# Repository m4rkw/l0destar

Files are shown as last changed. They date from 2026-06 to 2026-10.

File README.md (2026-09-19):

# l0destar

[l0destar.com](https://l0destar.com) A fully open-source vehicle tracker - open hardware and open software.

Inspired by the [Geolink Opentracker](https://github.com/geolink/opentracker/) and the [Fortebit Polaris](https://www.fortebit.tech/polaris/), the goal is to build something that will last: a reference design for the best possible vehicle tracker that anyone can fab, modify, and host. Hardware and software are completely open and maintained as a community project.

## Status

Prototyping / design phase. The v2.1 layout worked on a bench, and v2.6 (CAN,
K-line and micro), v3.0, v3.1, v3.2 and v3.3 have since been built and bench
tested - see the test status table in each board's README. v3.4 is designed
but not yet built or tested.

<strong>All boards before v3.3 have a serious defect in the K-wire circuit
if the L wire is connected. If any of these prototypes are built the L wire
should not be connected to the vehicle as if it was ever externally shorted
to the 12V rail the l0destar device would be damaged.</strong> Luckily very
few people are going to care at all about this ancient protocol and even fewer
will ever need the L wire in normal use but it still bears mentioning as an
indication that these are very much prototypes and there may be other
undiscovered defects.

## Disclaimer

This is a prototype, not a product. Nothing here is validated, qualified or certified, the parts lists are examples rather than a verified BOM, and any test results are my own unverified bench observations. All responsibility for anything built from it rests with the person building and installing it.

**Before building, installing or relying on any of this, read the [full disclaimer](DISCLAIMER.md).**

## What it is

- **Mission** - the world's best fully open-source vehicle tracker, no profit motive. See [`MISSION.md`](MISSION.md).
- **Goals** - KiCad reference design, open enclosure CAD, open firmware and server, weeks of standby on a typical car battery, 1 Hz GNSS, LTE-M/NB-IoT, CAN + K-Line diagnostics, accelerometer-driven wake. Full list in [`GOALS.md`](GOALS.md).
- **Technology choices** - Nordic nRF9151 SiP (LTE-M/NB-IoT + GNSS), LT8609A buck, ASM330LHHX IMU, MCP2518FD + TCAN3414 CAN, TJA1027T K-Line. Rationale and trade-offs in [`TECHNOLOGY.md`](TECHNOLOGY.md).

## License

l0destar is multi-licensed by artifact type - permissive across the board:

| Artifact | License |
|---|---|
| Hardware design files | `CERN-OHL-P-2.0` |
| Firmware | `Apache-2.0` |
| Server-side software | `Apache-2.0` |
| Documentation, enclosure CAD, media | `CC-BY-4.0` |

Full text and rationale in [`LICENSE.md`](LICENSE.md); license bodies in [`LICENSES/`](LICENSES/).

## Contributing

Contributions are welcome. l0destar uses the [Developer Certificate of Origin](https://developercertificate.org/) rather than a CLA - every commit must carry a `Signed-off-by:` trailer (`git commit -s`). See [`CONTRIBUTING.md`](CONTRIBUTING.md) for PR expectations.

## Contact

- Bug reports and feature ideas: [GitHub Issues](https://github.com/m4rkw/l0destar/issues)
- Open-ended questions and design discussion: [GitHub Discussions](https://github.com/m4rkw/l0destar/discussions)
- Direct contact: [contact me](https://l0destar.com/contact.html)

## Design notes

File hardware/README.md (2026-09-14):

# l0destar hardware

**Before building, installing or relying on any of this, read the [project disclaimer](../DISCLAIMER.md).**

## Overview

KiCad PCB designs for the l0destar vehicle tracker. All boards are built around
the Nordic nRF9151 for LTE-M/GPS and share a common set of subsystems: 12V
automotive power input, INA228 voltage monitoring, ignition sensing, and an
accelerometer/IMU.

**THESE SHOULD NOT BE CONSIDERED FINISHED PRODUCTS. SOME OF THEM HAVEN'T BEEN
TESTED AT ALL. USE ENTIRELY AT YOUR OWN RISK.**

**SOME OF THESE HAVE KNOWN DEFECTS DETAILED IN THEIR README**

Prototypes here are currently being tested and evaluated, there are typically a
few in the pipeline at any given time. Older boards no longer being tested are
moved into the [archive](archive/).

## PCB designs

### v3.1 - input resilience, hardened antenna feed, aux rail fault detection

- **[l0destar v3.1](l0destar_v3.1/)** - v3.0 with more robust input protection
  (sized for ISO 7637-2 pulse 2a), auxiliary power rail sensing/fault
  detection, and a hardened antenna feed with 15R series resistance and ESD
  protection. Same footprint as v3.0. Tested - 130 µA quiescent, all major
  subsystems passed.

### v3.2 - MCU over-voltage protection

- **[l0destar v3.2](l0destar_v3.2/)** - v3.1 plus hardware over-voltage
  protection that disconnects the module supply within microseconds of a
  regulator fault (self-recovering, no firmware dependency, ~10 µA), and I2C
  bus hardening against LTE TX bursts (stronger pull-ups, 100pF filter caps
  on SDA/SCL, series jumper/ferrite on the accelerometer supply).

  Tested successfully: <a href="https://www.youtube.com/watch?v=6-iVvQPaaeg">OVP scope test</a>.
  134 µA quiescent with firmware 0.4.26 (140.8 µA before it moved the sleep
  wake interrupts off the GPIOTE channels).

### v3.3 - L-line defect fix

- **[l0destar v3.3](l0destar_v3.3/)** - fixes the L-line short-to-battery
  defect present in v3.0-v3.2 (pulldown current limited to 90 mA via an
  AL5809-90, gate-fault current into the nRF limited) and adds L-line fault
  sensing so a 12V short can be detected. Buck converter tuned to shut off
  cleanly below ~4.3V and restart only above ~5.6V to avoid flapping. Built and
  bench tested: 146.2 µA quiescent as built, 43.7 µA with the accelerometer's
  NC pads scraped off.

### v3.4 - accelerometer fix

- **[l0destar v3.4](l0destar_v3.4/)** - v3.3 with the accelerometer's NC pins
  left unconnected (grounded on v3.0-v3.3, which kept the part out of its
  low-power state), the buck enable divider made optional, test points added
  and a TCAN3414DR CAN transceiver specified. Not yet built or tested; ~35.5 µA
  quiescent expected at 12V.

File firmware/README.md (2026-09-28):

# l0destar firmware

**Before building, installing or relying on any of this, read the [project disclaimer](../DISCLAIMER.md).**

Automotive telemetry tracker firmware for the **Nordic nRF9151** SiP (LTE-M +
GNSS), built on Zephyr RTOS via the nRF Connect SDK (NCS). It reports position,
speed, battery and ignition state to a back-end over an encrypted link, sleeps
deeply when the vehicle is parked, and wakes on movement, ignition, or a timer.

> Ported from the original Arduino/Polaris `*.ino` firmware. Where a module
> replaces a legacy one, its header comment notes the original source file.

---

## Hardware

| Function | Part / detail |
|---|---|
| MCU / modem / GNSS | nRF9151 SiP (LTE-M, integrated GNSS receiver) |
| IMU | ASM330LHHX (automotive 6-axis, WHO_AM_I 0x6B) over bit-banged I²C - accelerometer for movement detection, the wake interrupt and impacts; gyro in telemetry and impact alerts; FIFO as a ring of recent samples; MLC/FSM unused |
| Voltage monitor | INA228 over the same I²C bus - battery / ignition-derived voltage |
| Diagnostics | K-wire (ISO 14230-1 K-line, KWP2000) via TJA1027T on v3.x (L9637D on v2.x); 5-baud address bit-banged, data bytes on UARTE1 — see [KWIRE.md](KWIRE.md) |
| Ignition sense | GPIO input (MOSFET-gated 3.3 V rail) |
| Status LED | board `led0` alias (LED1 on the nRF9151 DK) |

Builds target the **Makerdiary nRF9151 Connect Kit** (`nrf9151_connectkit/nrf9151/ns`),
which every l0destar carrier board is built around; `PROFILE=dk` builds for the
nRF9151 DK instead. Pin assignments come from `Kconfig.boards` and are given
names in `src/pins.h`; DK-specific peripheral conflicts are resolved in
`boards/nrf9151dk_nrf9151_ns.overlay` (+ `.conf`).

### Carrier boards

Every l0destar PCB carries the same Connect Kit but lands each signal on a
different header pin and wires the switched power rails differently.
`Kconfig.boards` defines one selectable definition per PCB - GPIO map,
fitted-hardware flags, and power-domain topology, all extracted from the KiCad
designs in `../hardware/`. Select the board in `local.conf` and everything
else follows:

```
CONFIG_APP_BOARD_L0DESTAR_V3_0=y
```

Available: `APP_BOARD_BENCH`, `..._L0DESTAR_V2_1`, `..._V2_1_MINI`,
`..._V2_5_CAN/_KLINE/_MICRO`, `..._V2_6_CAN/_KLINE/_MICRO`, `..._V3_0`,
`..._V3_1`, `..._V3_2`, `..._V3_3`, `..._V3_4` (default).
Individual pins/flags can still be overridden after the board defaults apply
(on v3.0, set `CONFIG_APP_BOARD_HAS_CAN=n` or `..._HAS_KLINE=n` to match the
jumper configuration of the physical board).

Selecting a board also arms the **power-domain sequencing** in
`src/hw_domain.c`. Signals that terminate inside a switched rail (CAN SPI
pins, K-line pins) are parked as input+pulldown whenever that
rail is off and only released while it is powered - a pin driven high into an
unpowered MCP2518FD/TXS0104E would backfeed the dead rail through its ESD
clamp diodes (abs max VDD + 0.3 V), and the CAN_INT/CAN_CS/K-line pull-ups
live on the switched rails, so they float when the domain is down. On boards
with transceiver standby control (v2.5C/v2.6C, and v3.0 onwards),
`src/hw_can.c` configures MCP2518FD `IOCON.XSTBYEN` at boot so sleep mode
automatically drops the transceiver into standby - required on v2.5/v2.6
where the CAN rail shares the GPS AUX domain and stays powered during
engine-off telemetry wakes.

---

## Architecture

`main()` initialises the peripherals, modem, GNSS and watchdog, then runs a
state machine:

```
            ┌───────────────────────────── engine on ──────────────┐
            ▼                                                        │
  IDLE ──► GPS_COLLECT ──► SEND ──┬─► (ignition off) ─────► SLEEP    │
   ▲                              ├─► (engine off)  ─► IGNITION_SLEEP┘
   └──────────────────────────────┘
```

- **IDLE** – wait for network registration, poll ignition + battery, decide when to send.
- **GPS_COLLECT** – acquire a GNSS fix, build and buffer a telemetry record.
- **SEND** – transmit batched telemetry over encrypted UDP, process any server command.
- **IGNITION_SLEEP** – ignition on but engine off: periodic sends, watch for engine start / ignition off.
- **SLEEP** – ignition off: peripherals powered down; wakes on the IMU's movement interrupt, ignition change, or telemetry timer.

Extras handled in the loop: **movement alarm** with escalating cooldowns,
**coast-to-stop** (keep reporting briefly after ignition-off while still
rolling), and **modem recovery**: registered but unable to send for
`APP_MODEM_STUCK_CFUN_S` (10 min) brings a CFUN cycle, and for
`APP_MODEM_STUCK_RESET_S` (30 min) a modem library restart. Losing coverage is
left to the modem.

### Impact detection

While awake the IMU runs at ±8 g with a high-g interrupt
(`APP_CRASH_THRESHOLD_MG`, default 4 g - set ~1200 in `local.conf` and rap the
desk to bench-test) and batches accel+gyro at 26 Hz into the chip's 3 KB FIFO
ring (~9 s of history). On impact, the ring is drained and an alert is sent
with peak g (per-axis), peak rotation rate, disturbance duration, and speed;
the ±0.5 s waveform around the peak is dumped to the serial log. While asleep,
a short, sharp hit above `APP_IMPACT_IMMEDIATE_MG` (default 700 mg) is reported
at once, and an unconfirmed movement wake whose peak exceeds
`APP_PARKED_IMPACT_MG` (default 800 mg) raises a `parked impact` alert instead
of being ignored. Telemetry `ax/ay/az` are **milli-g** (FS-independent);
`gx/gy/gz` are bias-corrected LSB at ±250 dps.

### Source layout (`src/`)

| File | Description |
|---|---|
| `main.c` | Entry point, state machine, sleep/wake, movement + coast logic |
| `modem.c` | LTE-M bring-up, registration, APN, RAI, cell-info tracking, error recovery |
| `gnss.c` | GNSS fixes via the nRF9151's built-in receiver (`nrf_modem_gnss`) |
| `agnss.c` | A-GNSS assistance from **nRF Cloud REST** (device-JWT auth) |
| `transport.c` | UDP telemetry, each datagram sealed with **ChaCha20-Poly1305** under the device key |
| `traccar.c` | Built in its place with `CONFIG_APP_TRACCAR`: the same lines as OsmAnd-protocol HTTP requests to a **Traccar** server ([TRACCAR.md](TRACCAR.md)) |
| `data.c` | Telemetry CSV record builder (position, speed, battery, ignition, accel) |
| `commands.c`  | Server command dispatch (`key=value[,…]`) |
| `alert.c` | Movement/event alert queue (piggybacks on sends, or standalone) |
| `settings.c`  | Runtime settings (in-memory; Kconfig-backed defaults) |
| `crypto.c` | ChaCha20-Poly1305 through PSA Crypto, CSPRNG, PSK hex parsing |
| `hw_common.c` | GPIO init + bit-banged I²C bus |
| `hw_domain.c` | Switched power-domain sequencing (park/release of pins in AUX/OBD/K domains) |
| `hw_power.c`  | INA228 voltage, ignition read, INA shutdown/wake, AUX domain wrappers |
| `hw_can.c` | MCP2518FD power/domain handling, sleep mode + transceiver standby (XSTBY) |
| `hw_accel.c`  | ASM330LHHX IMU (accel path): polling + hardware wake interrupt |
| `hw_kline.c`  | K wire: 5-baud init bit-banged, data bytes on UARTE1; vehicle discovery and the runtime session ([KWIRE.md](KWIRE.md), [KWIRE_QUICKSTART.md](KWIRE_QUICKSTART.md)) |
| `kline_obd.c` | OBD-II over the K wire: PID polling into telemetry, fault codes, engine/speed for the tracker's own logic; the fast rotating poll for track mode ([TRACK_MODE.md](TRACK_MODE.md)) |
| `obd_alert.c` | Threshold alerts on OBD telemetry: the `CONFIG_APP_OBD_ALERTS` rule list judged after every poll, one alert per crossing with a clear on the way back |
| `fota.c` | Over-the-air updates: manifest check, battery gate, MCUboot image download ([FOTA.md](FOTA.md)) |
| `databuf.c` | Backlog of records that could not be sent, kept until the link comes back |
| `dbglog.c` | Keeps warnings and errors in RAM and sends them with the next record that gets through |
| `fatal.c` | Fatal error handler: reboots instead of halting, leaving a note for the next record's `rst=` field |
| `hw_selftest.c` | Boot-time switched-rail self-test (v3.1+) |
| `board_test.c` · `lte_power_test.c` · `can_bench.c` | Bench builds only: the interactive board test run by `board_test.sh` · LTE transmit power and brown-out rig · CAN bench-test agent |
| `led.c` · `watchdog.c` · `reboot.c` | Status LED · 32 s task watchdog (HW fallback) · reboot helper |
| `config.h` · `pins.h` · `app.h` · `ca_cert.h` | Compile-time defaults · names for the `APP_PIN_*` pins · shared API/state · server CA cert, generated from `certs/ca.crt` by `build.sh` and not in git |

---

## Connectivity & telemetry

Telemetry is **plain UDP**, each datagram sealed with **ChaCha20-Poly1305**
under the device's 32-byte key, `CONFIG_APP_PSK_HEX` (`transport.c`,
`crypto.c`). The server holds the same key for the device's IMEI, so a datagram
that decrypts is authenticated as well as private.

- Endpoint: `CONFIG_APP_SERVER_HOST` : `CONFIG_APP_SERVER_PORT` (**65480**).
- Request: `[1] IMEI length` `[n] IMEI` `[12] nonce` `ciphertext` `[16] tag`, with
  the IMEI as associated data. Response: `[12] nonce` `ciphertext` `[16] tag`,
  bound to the IMEI and the request's nonce. See
  [PROTOCOL.md](../server/docs/PROTOCOL.md).
- `modem.c` enables release assistance (`AT%RAI`), so the radio is released
  soon after each exchange and GNSS gets the shared antenna back.
- Delivery is confirmed, not assumed. The modem accepting a datagram only
  means it is queued, and a modem that loses its registration discards what
  it holds, so each send's records are kept until the server's reply to that
  datagram comes back (the reply is bound to the request's nonce, so it names
  the datagram) and sent again from the backlog if it has not within
  `APP_ACK_TIMEOUT_S` (`databuf.c`). The server drops the copy of anything
  that did arrive, and a record sent late carries `age=` so it is filed at
  the time it was built. A drive that loses the network keeps recording into
  the backlog.

The CA in `src/ca_cert.h` is for updates only: `modem.c` writes it into the
modem on first boot, and the update server's certificate is checked against it.

**Traccar** instead of the l0destar server: `CONFIG_APP_TRACCAR=y` with
`CONFIG_APP_TRACCAR_HOST` builds `src/traccar.c` in place of `transport.c`,
and every record, alert and fault-code report goes to a
[Traccar](https://www.traccar.org) server as an OsmAnd-protocol HTTP request
(port 5055), with the device's IMEI as its identifier. Records, batching and
the backlog are unchanged; Traccar's *custom* command reaches the firmware's
command parser. What the l0destar server does that Traccar cannot — settings
from the server, track mode, update adverts, the device log, encryption — is
in [TRACCAR.md](TRACCAR.md), with the field mapping.

Each telemetry record is one CSV line built in `data.c` (timestamp, lat, lon,
speed, altitude, heading, HDOP, satellites, battery, ignition, uptime and
power-on flag, then extras such as the accelerometer;
[PROTOCOL.md](../server/docs/PROTOCOL.md) lists them all). Records batch by `BATCH_SIZE` (`CONFIG_APP_BATCH_SIZE`,
default 3 while driving: each send costs an RRC connection and a GNSS
re-acquisition, so three records a datagram roughly doubles the record rate
for a page update every few seconds; ignition changes and settings syncs
still flush at once).

---

## GNSS & A-GNSS (nRF Cloud)

GNSS fixes come from the nRF9151's built-in receiver. A cold fix with no cached
ephemeris can take 2–5 minutes (it time-shares the antenna with LTE), so the
firmware optionally fetches **A-GNSS** assistance from nRF Cloud to speed up
time-to-first-fix.

`agnss.c` authenticates to nRF Cloud's REST API with a **per-device JWT** signed
by a key in the modem at `CONFIG_NRF_CLOUD_SEC_TAG` (default `16842753`). nRF
Cloud only accepts that JWT once the device has been **onboarded** to your
account - otherwise the request fails with `401 / 40100 "Auth token is
malformed"`. See **[nRF Cloud device provisioning](#nrf-cloud-device-provisioning)**.

> A-GNSS is an optimisation, not a dependency: GNSS still cold-fixes without it.

---

## Building

Requires [nRF Connect SDK **v3.3.0**](https://docs.nordicsemi.com/) where nRF
Util's sdk-manager installs it: `/opt/nordic/ncs/v3.3.0` on macOS, `~/ncs/v3.3.0`
on Linux (override with `NCS_ROOT`). Builds target the Connect Kit; `PROFILE=dk`
builds for the nRF9151 DK, and `BOARD` overrides the target.

```sh
./build.sh            # incremental build  -> build/merged.hex
./build.sh pristine   # clean rebuild
```

`build.sh` runs `west build` inside the NCS toolchain. It layers `local.conf`,
and stops if there is none unless `LOCAL_CONF` is set empty; `PROV=1` adds
`prov.conf` on top.

### Configuration layers

| File | Committed | Purpose |
|---|---|---|
| `prj.conf` | yes | Zephyr/NCS subsystem config (modem, sockets, crypto, logging, PM) |
| `Kconfig`  | yes | Application symbols + defaults (see table below) |
| `boards/nrf9151dk_nrf9151_ns.{conf,overlay}` | yes | Board-specific Kconfig + devicetree (disables conflicting DK peripherals) |
| `boards/nrf9151_connectkit_nrf9151_ns.conf` | yes | Connect Kit builds: turns on the modem antenna library and sends `AT%XCOEX0`, which powers the GNSS amplifier |
| `local.conf` | **no** (git-ignored) | Per-deployment secrets / overrides |
| `prov.conf`  | yes | Provisioning-build overlay (AT-host bridge) - enabled via `PROV=1` |

The full list, with `remote.conf`, `sysbuild.conf` and `pm_static.yml`, is in
[firmware build options](../docs/reference/firmware.md).

### local.conf

`local.conf` is git-ignored; create it with at least the board, the server, the
APN and the device key:

```
CONFIG_APP_BOARD_L0DESTAR_V3_4=y
CONFIG_APP_SERVER_HOST="tracker.example.com"
CONFIG_APP_APN="iot.example.net"
CONFIG_APP_PSK_HEX="<64 hex characters>"
```

Any `APP_*` symbol from `Kconfig` can be overridden here (see the reference
table). `CONFIG_APP_PSK_HEX` is required: the server decrypts this device's
telemetry with the same key, which it is given when the device is enrolled
(`openssl rand -hex 32` makes one).

### Flashing

```sh
./flash.sh                          # program over the Connect Kit's CMSIS-DAP probe
./reset.sh                          # reboot without reflashing
```

Both use pyocd and end with a pin reset: pyocd's default soft reset leaves the
nRF9151 in debug interface mode, drawing milliamps while asleep.
[QUICKSTART.md](QUICKSTART.md) explains why they also stop pyocd erasing a
protected part.

---

## Over-the-air updates

The build carries **MCUboot** (`sysbuild.conf`), which splits the 1 MB flash
into two 416 KB slots pinned by `pm_static.yml`. `fota.c` checks for an update
at power-on, when sent the `fota` command, and at the next safe moment after a
telemetry reply advertises a newer version (`fota=<version>`). It fetches its
own manifest from the update server (`CONFIG_APP_FOTA_HOST`, by default the
telemetry host) on TCP 65481 over TLS, and installs a newer image built for its
board - provided the battery is above `CONFIG_APP_FOTA_MIN_BATTERY_MV`
(12.0 V). A swapped image that never finishes booting is rolled back
automatically.

The firmware version lives in one place, the `VERSION` file, which holds
`MAJOR.MINOR`; `build.sh` adds the patch number, and the result feeds
`<zephyr/app_version.h>`, the MCUboot image header and the version comparison.
`push_fw.sh` derives the patch number from what the server has already
published, so bump the minor version to restart the count.

> The first build with MCUboot has to be flashed over SWD - a unit running a
> pre-MCUboot image has no bootloader to swap slots.

See **[FOTA.md](FOTA.md)** for the manifest format, the server requirements
(range requests are mandatory over TLS), the release procedure and the signing
key.

---

## nRF Cloud device provisioning

One-time per device, to enable A-GNSS. The device's key/cert are written to
**modem NVM**, so they survive reflashing the application. No separate
`at_client` sample is needed - a provisioning build of *this* firmware acts as
the AT bridge.

**Prerequisites**

- An nRF Cloud account and its **REST API key** (nrfcloud.com → User Account).
- [`nrfcloud-utils`](https://pypi.org/project/nrfcloud-utils/): `uv tool install --python 3.12 nrfcloud-utils`

**1. Create a device CA (once)**

```sh
mkdir -p onboarding
create_ca_cert -c GB -o l0destar -p onboarding -f l0destar
```

Writes `onboarding/*_ca.pem` / `*_prv.pem` (git-ignored - the key is secret).

**2. Build & flash the provisioning firmware**

```sh
PROV=1 BUILD_SUBDIR=build_prov ./build.sh
pyocd load -t nrf91 --no-reset build_prov/merged.hex
pyocd reset -t nrf91 -m hw -O auto_unlock=false
```

It boots into "PROVISIONING MODE", with the AT host on the console port. The
build goes into its own directory, leaving your normal `build/` alone, and the
two pyocd commands are what `flash.sh` does, pointed at this build.

`prov.conf` enables `CONFIG_AT_HOST_LIBRARY`, disables logging (clean UART), and
`main()` idles after `modem_init()` so the AT exchange isn't corrupted.

**3. Free the serial port, then install credentials**

> ⚠️ Any serial monitor holding the port (e.g. a `cat`/logger daemon) will
> race the installer and corrupt the CSR. Stop it first.

```sh
device_credentials_installer \
  --port /dev/cu.usbmodemXXXX --cmd-type at \
  --ca     onboarding/*_ca.pem \
  --ca-key onboarding/*_prv.pem \
  --id-imei --id-str nrf- \
  -S 16842753 -d \
  --csv onboarding/onboard.csv --verify
```

`--id-imei --id-str nrf-` produces device ID `nrf-<IMEI>` and `-S 16842753`
matches the firmware's JWT sec-tag - both **must** match or nRF Cloud rejects
the JWT.

**4. Register the device to your account**

```sh
nrf_cloud_onboard --api-key "$NRF_CLOUD_API_KEY" --csv onboarding/onboard.csv
# verify:
curl -s "https://api.nrfcloud.com/v1/devices" -H "Authorization: Bearer $NRF_CLOUD_API_KEY"
```

**5. Reflash the normal firmware**

```sh
./flash.sh                          # build/ still holds the tracker build
```

On the next cold boot the A-GNSS fetch authenticates with the device JWT and
returns assistance data (`agnss: received … bytes` → `A-GNSS data injected`).

---

## Configuration reference (`Kconfig`)

| Symbol | Default | Meaning |
|---|---|---|
| `APP_LOG_LEVEL` | 3 | App module log level (0=off … 4=dbg) |
| `APP_PROVISION_MODE` | n | Build as the AT-host provisioning bridge (set via `prov.conf`) |
| `APP_PIN_*` | PCB map | Every signal's P0.x GPIO (K-line, I²C, IMU INTs, ignition) - remap per-board in `local.conf` |
| `APP_DEBUG_IGNITION` | -1 | Force ignition state (0=ON, 1=OFF, -1=live GPIO) |
| `APP_DEBUG_BATTERY_MV` | 0 | Force battery voltage in mV (0=live INA228) |
| `APP_DEBUG_DROP_DATAGRAMS` | 0 | Bench only: discard every Nth datagram as if lost, to exercise the resend (0 = never) |
| `APP_CRASH_THRESHOLD_MG` | 4000 | Impact alert threshold while awake (mg) |
| `APP_PARKED_IMPACT_MG` | 800 | Parked-impact threshold from FIFO peak (mg) |
| `APP_IMPACT_IMMEDIATE_MG` | 700 | Parked hit reported without waiting for the movement confirm (mg, 0 = never) |
| `APP_DEMO_MODE` | n | Mask lat/lon in the serial log (public demos); telemetry unaffected |
| `APP_SERVER_HOST` | "" | Telemetry hostname (else `HOSTNAME` in `config.h`) |
| `APP_SERVER_PORT` | 65480 | Telemetry UDP port |
| `APP_APN` | "" | Cellular APN (else `DEFAULT_APN`) |
| `APP_TRACCAR` | n | Report to a Traccar server (OsmAnd protocol over HTTP) instead of the l0destar server ([TRACCAR.md](TRACCAR.md)) |
| `APP_TRACCAR_HOST` / `_PORT` | "" / 5055 | The Traccar server and its OsmAnd listener's port |
| `APP_TRACCAR_ID` | "" | Device identifier in Traccar (empty = the IMEI) |
| `APP_TRACCAR_SEC_TAG` | -1 | Modem sec_tag holding the CA for HTTPS to Traccar; -1 = plain HTTP |
| `APP_PSK_HEX` | "" | Device key, 64 hex characters: required, and must match the server's |
| `APP_ENGINE_OFF_LOOP_INTERVAL` | 0 | Engine-off wake interval until the server sets one (s; 0 = 3600) |
| `APP_IGNITION_ON_SLEEP_INTERVAL` | 30 | Send cadence: ignition on, engine off (s) |
| `APP_VOLTAGE_POLL_INTERVAL` | 5 | Battery sample cadence in IDLE (s) |
| `APP_BATTERY_CHECK_INTERVAL` | 86400 | Battery check during deep sleep (s) |
| `APP_NETWORK_REGISTRATION_TIMEOUT` | 60 | Registration timeout (s) |
| `APP_NETWORK_RETRY_INTERVAL` | 300 | Network retry interval (s) |
| `APP_NETWORK_SEARCH_TIMEOUT` | 300 | With the ignition off, how long the modem may search for a network before the unit powers it off and sleeps (s; 0 = no limit) |
| `APP_NO_SIGNAL_MAX_INTERVAL` | 86400 | Ceiling on the engine-off wake interval while there is no network: each dead wake doubles the wait up to this (s; 0 = no backoff) |
| `APP_SIGNAL_SAMPLE_S` | 60 | Seconds between serving-cell signal readings (`AT%XMONITOR`, free on the radio). 0 = only when the cell context is refreshed |
| `APP_CONN_EVAL` | n | Also report path loss, RSRQ, CE level and TX repetitions. Costs an evaluation and is refused while the radio is busy |
| `APP_NCELLMEAS` | n | Diagnostic: measure neighbouring cells once per wake and report the count and the strongest. Runs a real scan |
| `APP_PSM_PROBE` | n | Diagnostic: request PSM and report what the network grants (`APP_PSM_PROBE_TAU_S` / `_ACTIVE_S`). Does not adopt PSM — sleep still ends at CFUN=0, so nothing about sleep current or wake behaviour changes |
| `APP_GPS_FIX_TIMEOUT_MS` | 60000 | GNSS fix timeout (ms) |
| `APP_GPS_COLD_FIX_TIMEOUT_MS` | 300000 | Cold-start fix timeout (ms) |
| `APP_BATTERY_WARNING_MV` / `_POWEROFF_MV` | 11900 / 11800 | Battery warning / power-off (mV) |
| `APP_SLEEP_SAFETY_MV` | 12000 | Skip-send threshold while sleeping (mV) |
| `APP_ENGINE_RUNNING_MV` | 13000 | Engine-running voltage threshold (mV) |
| `APP_BACKUP_SUPPLY` | n | Inline battery backup module fitted: 8.5-9.7 V (`APP_BACKUP_MIN_MV`/`_MAX_MV`) with the ignition off is backup power, not a flat battery |
| `APP_ACC_MOVEMENT_THRESHOLD` | 150 | Movement delta threshold (milli-g) |
| `APP_MOVEMENT_CONFIRM_MS` / `_HITS` | 10000 / 6 | Movement confirmation window / samples |
| `APP_MOVEMENT_INACTIVITY_RESET` | 1800 | Inactivity reset timer (s) |
| `APP_MOVEMENT_ALARM` | n | Enable movement alarm |
| `APP_COAST_STOP_SPEED_KMH_X10` | 50 | Coast-to-stop speed threshold (km/h ×10) |
| `APP_COAST_MAX_ITERATIONS` | 60 | Coast-to-stop max iterations |
| `APP_BATCH_SIZE` | 3 | Records per datagram while driving |
| `APP_DATABUF_UNACKED_SLOTS` | 6 | Sent datagrams whose records are held until the server answers (0 = take a send at its word; 0 under Traccar, whose HTTP 2xx is the receipt) |
| `APP_ACK_TIMEOUT_S` | 30 | Seconds without an answer before a datagram's records go back to the backlog to be sent again |
| `APP_MODEM_STUCK_CFUN_S` | 600 | Registered but unable to send this long: CFUN cycle (s) |
| `APP_MODEM_STUCK_RESET_S` | 1800 | Registered but unable to send this long: modem restart (s) |

---

## Logging / serial

The console and logs are on the first of the Connect Kit's two USB serial ports
(the J-Link VCOM on the DK) at **115200 baud, 8-N-1**. macOS resets a serial
port to 9600 baud whenever it is opened, so use a terminal that holds the port
open, such as `screen /dev/cu.usbmodemXXXX 115200`.

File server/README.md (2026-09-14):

# l0destar server

Backend for the l0destar tracker: telemetry ingestion, storage, alerting,
over-the-air firmware delivery, and a map UI.

Self-hosted by design. There is no cloud service to sign up for and no
account anywhere but your own — which is most of the point of the project. A
vehicle tracker publishes where you are in real time, and that data should
live on hardware you control.

> **Status: draft.** This is a public implementation derived from a working
> private deployment. It is refactored and de-personalised rather than
> line-for-line, and has not been run end to end against real hardware in this
> form. Treat it as a reference to read and adapt, not something to point a
> vehicle at unreviewed.

## What it does

- **Ingests telemetry** over UDP with ChaCha20-Poly1305, under a key per
  device; see [`docs/PROTOCOL.md`](docs/PROTOCOL.md).
- **Stores** positions, IMU, cell, thermal and power telemetry, and derives
  journeys from ignition transitions.
- **Alerts** on ignition, movement and low battery, through Pushover, a
  webhook, or nothing at all.
- **Delivers firmware** as per-device signed images with range support, over
  TLS.
- **Serves a map** with live position over a WebSocket and journey replay.
- **Tracks several vehicles**: a device list, a map per vehicle, and an API
  that is told which device each request is about.
- **Queues commands** for delivery on a device's next check-in.

Authentication is passkeys only. There is no password column in the schema.

## Layout

```
tracker/            application package
  config.py           configuration loading
  db.py               MySQL handles, device and operator lookup
  logs.py             per-channel log files
  notify.py           pluggable outbound notifications
  telemetry.py        parsing, storage, journeys, response building
  firmware.py         OTA manifests and the firmware HTTP server
  listeners/          udp.py (telemetry), tls.py (firmware downloads)
  web/                Flask app, passkey auth, JSON API, WebSocket
tools/              enrolment and operations scripts
Dockerfile          the m4rkw/l0destar image
docker/             the image's entrypoint and database settings
deploy/             nginx, systemd and launchd examples
docs/PROTOCOL.md    the device-facing wire protocol
schema.sql          MySQL schema
wsgi.py             entrypoint
```

The listeners and the web application share the telemetry layer and nothing
else; either runs without the other.

## Running it with Docker

The `m4rkw/l0destar` image runs the server together with the MariaDB it
stores everything in, and keeps everything in the host directory mounted at
`/data`:

```sh
sudo install -d -o "$USER" -g "$USER" /srv/l0destar
sudo docker run -d --name l0destar --restart unless-stopped \
    -e L0DESTAR_HOSTNAME=tracker.example.com \
    -v /srv/l0destar:/data \
    -p 65480:65480/udp -p 65481:65481/tcp -p 127.0.0.1:5000:5000 \
    m4rkw/l0destar
```

The first start writes `config.yaml`, creates a CA and a certificate for
`L0DESTAR_HOSTNAME` in `certs/`, and creates the database; every start applies
any migrations the database has not had. The server and the database run as
the owner of the data directory. The tools run inside the container:

```sh
sudo docker exec l0destar python tools/adddevice.py 350000000000000 "Car" AB12CDE
```

The full walkthrough is [`docs/server/installation.md`](../docs/server/installation.md),
and [`docker/entrypoint.sh`](docker/entrypoint.sh) is what runs at start-up.
To build and publish the image for both architectures:

```sh
docker buildx build --platform linux/amd64,linux/arm64 -t m4rkw/l0destar --push .
```

## Running it from a checkout

Requires Python 3 (developed and tested on 3.12) and MySQL or MariaDB.

```sh
uv venv --python 3.12 .venv
uv pip install --python .venv/bin/python -r requirements.txt

mysql -u root -p -e "CREATE DATABASE tracker CHARACTER SET utf8mb4"
mysql -u root -p tracker < schema.sql

cp config.yaml.example config.yaml
chmod 600 config.yaml
$EDITOR config.yaml          # at minimum: session_secret, database
```

Enrol a device and a user:

```sh
.venv/bin/python tools/adddevice.py 350000000000000 "Car" AB12CDE
.venv/bin/python tools/regtoken.py alice tracker.example.com
```

The tools run on the venv's interpreter: their `#!/usr/bin/env python3` line
would find a Python without the dependencies.

`adddevice.py` prints a pre-shared key once — it has to be built into that
unit's firmware and is not shown again. Enrol every vehicle the same way; each
gets its own key. `regtoken.py` prints a single-use enrolment URL valid for 24
hours; open it on the device that will hold the passkey, at the hostname people
will use to reach the server, because the passkey is bound to it.

Run it:

```sh
.venv/bin/gunicorn -c gunicorn.conf.py wsgi:app
```

`TRACKER_BIND` (`127.0.0.1:5000`), `TRACKER_WORKERS` (2) and `TRACKER_THREADS`
(16 per worker) size it. Every open map page holds a thread for its WebSocket,
which is why the workers are threaded; the telemetry listeners run once, in the
gunicorn master.

`deploy/` has nginx, systemd and launchd examples. Put nginx in front of the
web UI; the telemetry listeners bind their own ports and want forwarding at
the firewall rather than proxying.

### Certificates

For firmware downloads the device needs to trust the server. The firmware
embeds a CA certificate, so a self-signed CA is the simplest thing that works
and avoids depending on a public CA's renewal cadence for something that has
to keep working with a device in a car park. The Docker image creates one on
its first start. From a checkout, the usual place to make it is the firmware
tree, whose build embeds `firmware/certs/ca.crt`:

```sh
firmware/certs/gen_certs.sh tracker.example.com
```

Then copy `firmware/certs/server.crt` and `server.key` into this directory's
`certs/` (`tls_cert` and `tls_key`). The same script is here as
`certs/gen_certs.sh`; run from the server, it writes everything beside itself,
or to the directory given as its second argument, and `ca.crt` then goes to
`firmware/certs/ca.crt` on the build machine. Keys and certificates are
gitignored, and the firmware build generates `firmware/src/ca_cert.h` from
`ca.crt`, so no CA is ever committed.

## Migrations

`schema.sql` is the full current schema for a new database.  An existing one
takes the ALTER statements in `migrations/`, oldest first, each applied once.
The Docker image does that itself at start-up, and records what it applied in
`schema_migration`; a database without that record, such as one restored from
an older dump, gets every migration, skipping any change it already has. From a
checkout:

```
mysql -u root -p tracker < migrations/2026-09-06_track_mode.sql
```

## Operating

```sh
.venv/bin/python tools/device.py list                        # every vehicle, last seen
.venv/bin/python tools/device.py show 350000000000000        # settings, updates, queue
.venv/bin/python tools/command.py 350000000000000 int=3600   # engine-off interval
.venv/bin/python tools/command.py 350000000000000 locate     # position as an alert
.venv/bin/python tools/command.py 350000000000000 alarm=1    # notify on ignition
.venv/bin/python tools/gentoken.py home-automation           # bearer token for the API
.venv/bin/python tools/import_plmn.py plmn.csv               # operator names for the UI
```

With Docker, run the same tools as `sudo docker exec l0destar python tools/...`.

`device.py` also renames a device, replaces its key (`rekey`) and removes it
along with its history. `command.py` with no arguments lists every command.

Nothing is pushed to a device. It is asleep almost all of the time, so a
command waits in the queue until it next reports and rides back on the response
it was already going to receive — which at a long reporting interval can be an
hour away.

Logs are one file per channel under `log_dir`, plus `debug.log`, which only
receives records carrying debug counters or a reset cause. That keeps the
short chronological list of things that went wrong out of the bulk traffic.

## API

Browser endpoints are session-authenticated. Automation endpoints take
`Authorization: Bearer <token>` from `tools/gentoken.py`. Tokens are unscoped —
anything holding one can queue a command, so treat one as console-equivalent.

| Endpoint | Auth | Purpose |
|---|---|---|
| `GET /api/1.0/carpos` | session | latest position |
| `GET /api/1.0/journeys` | session | journey list, paged |
| `GET /api/1.0/journey/<id>/points` | session | one journey's track |
| `GET /api/1.0/devices` | session | every device with its latest record |
| `GET /api/1.0/status` | session | settings, firmware, last seen |
| `GET,POST /api/1.0/trackmode` | session | read or set the track-mode switch (`{"on": 1}`) |
| `GET /ws/carpos` | session | live position stream |
| `GET /api/1.0/track` | bearer | redirect to a map at the last fix |
| `GET,POST /api/1.0/config` | bearer | read and write device settings |
| `POST /api/1.0/command` | bearer | queue a command |
| `POST /api/1.0/home` | bearer | stalled-tracker watchdog, per `home_check` vehicle |

A request names its device with `imei` or `device_id`, in the query string or
a JSON body, or with an `X-Imei` header. A read that names none is answered
for `default_device`, or for the only enrolled device; a `POST` to `config`,
`command` or `trackmode` always has to name one. A named device that is not
enrolled is an error, never another vehicle's data.

The web UI itself is `/devices`, every vehicle with its last record, and
`/track?imei=<imei>`, one vehicle's map. `/` opens a map when there is one
obvious vehicle and the list otherwise.

## Tests

```sh
.venv/bin/pip install -r requirements-dev.txt
.venv/bin/pytest                      # parsing, crypto, OTA — no database
```

The integration tests need a throwaway database. They truncate every table
they touch, so do not point them at anything real:

```sh
mysql -u root -p -e "CREATE DATABASE tracker_test CHARACTER SET utf8mb4"
mysql -u root -p tracker_test < schema.sql
TRACKER_TEST_DB=root:pass@127.0.0.1:3306/tracker_test .venv/bin/pytest
```

The firmware tests drive the OTA HTTP server over a real socket rather than a
mock — what is being checked is byte-level framing, because the nRF91's
downloader is strict about `206` and `Content-Range` and a framing bug shows up
as a device that installs a corrupt image.

## Known gaps

- Nothing here has been run against real hardware in this form. The tests
  exercise the protocol against synthetic records, which is not the same as a
  device in a car park on a marginal cell.
- Journey `from_place` and `to_place` are in the schema but nothing fills them
  in — a deployment wanting place names needs its own geocoder.
- `log` grows without bound and there is no retention policy. A device
  reporting once a minute writes roughly half a million rows a year.
- Bearer tokens have no scopes or expiry.
- Every logged-in user can see and control every device; there are no
  per-user device permissions.

## Security notes

`config.yaml` holds every secret and is gitignored — keep it mode 600.
Certificates and private keys are gitignored too.

The app trusts `X-Forwarded-*` because passkeys bind to the origin. That is
only safe if the reverse proxy overwrites those headers and nothing else can
reach the backend port. Bind gunicorn to loopback — or, with Docker, publish
port 5000 on `127.0.0.1` only, since Docker opens the ports it publishes ahead
of the host firewall.

The TLS port has to be reachable from the internet for firmware downloads.
Firmware images are built with the device's pre-shared key inside, and that
port serves them to anyone who asks for a device's manifest - keep it closed
between rollouts if that exposure matters, and rekey a device whose image has
left your control (`tools/device.py rekey`).

If you find a security problem, please report it privately rather than opening
an issue — see the repository root.

## Licence

Apache-2.0, as the server-side component of
[l0destar](https://github.com/m4rkw/l0destar). See `LICENSE.md` at the
repository root.

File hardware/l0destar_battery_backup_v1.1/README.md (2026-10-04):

# l0destar battery backup v1.1

## Overview

**NOTE: v1.1 HAS NOT YET BEEN BUILT OR TESTED, USE AT YOUR OWN RISK.** It
fixes the three problems found building v1.0, see
[Changes from v1.0](#changes-from-v10)

- This is a prototype inline battery backup module for the l0destar vehicle
  tracker. It sits in the harness between the car and the tracker and holds
  the tracker's supply at ~9V from a single CR123A lithium primary cell when
  car power is cut
- It is designed to be hand-solderable (hot air required). Every active part
  is in a leaded package: MSOP-12, SOT-23, TSOT-23, SC70, DPAK
- The cell is a **non-rechargeable** primary in a board-mounted holder.
  Nothing on the board charges it. See [Why a primary cell](#why-a-primary-cell)
- Pin-compatible with the v3.4 tracker's 2x3 Micro-Fit harness: J1 takes the
  car harness, J2 goes to the tracker, the CAN/K-line pins pass straight
  through and ignition passes through a diode (S1D1)
- 4-layer 63.1 x 36.2 mm board, JLC04161H-7628 stack-up, four M2 mounting
  holes. PCB DRC is clean and schematic ERC has only the cosmetic
  `endpoint_off_grid` warnings

## Changes from v1.0

v1.0 was built and three problems came out of it. Same board outline,
connectors and enclosure; the cell, boost and wake-pulse circuits are
unchanged apart from reference designators.

1. **Pass-through dropped ~0.5V while the tracker slept.** The LM74610 is a
   floating controller that runs its charge pump from the forward drop across
   the FET, so at the tracker's sleep current it can't keep the gate enhanced
   and the current runs through the body diode instead. v1.1 replaces
   LM74610 + IRLR2905 (N-channel) with an LTC4412HV driving an SQD50P06-15L
   P-channel FET (S2U1/S2Q1). The LTC4412 regulates the FET to a ~20 mV
   forward drop at any load and drops the charge-pump capacitor (old S1C3).
   The trade is quiescent current: ~13 µA from the car where the LM74610 had
   none
2. **The ignition wake pulse didn't work.** The car pulls its ignition wire
   to ground when the key is off, so the pulse injected on IGN was simply
   sunk by the car's ignition loads. v1.1 adds S1D1, an S1B in series between
   J1 pin 5 (IGN\_CAR) and J2 pin 5 (IGN). Car ignition still reaches the
   tracker, a diode drop lower, and the car can no longer pull the pulse
   down
3. **The cell lockout caused brownouts, so it's gone.** Its ~50 µs input
   filter was short enough that boost inrush and LTE transmit sag pulled the
   cell below 2.45V and shut the boost off, which browned out the tracker.
   A single primary cell doesn't need protecting from running flat, so v1.1
   removes the lockout comparator, AND gate and restart pacing (old S5U3,
   S5U4, S5D1, S5R36, S5R37, S5R40, S5R41, S5C5, S5C6, S5C7). The car-sense
   comparator drives EN\_BOOST directly

Other changes:

- The input electrolytics are now hybrid polymer: S2C2 is 47 µF 63V
  Panasonic EEH-ZC1J470P (was EEE-FK1J470P) and S2C4 is 82 µF 63V
  Chemi-Con HHXC630ARA820MJA0G (was 100 µF EEE-FK1J101P)
- Reference designators are renumbered by sheet: S1 is the root sheet
  (connectors, S1D1, mounting holes), S2 pass-through, S3 cell, S4 boost,
  S5 wake pulse, S6 switchover

## Disclaimer

This is a prototype, not a product. Nothing here is validated or certified,
the parts lists are examples rather than a verified BOM, and every number
below is a desk calculation from datasheets rather than a bench measurement -
repeat the testing yourself rather than taking any of it on trust.

I strongly recommend not using unbranded CR123 cells or buying them from less
reputable sources.

**Before building or installing anything from this repository, read the
[full disclaimer](../../DISCLAIMER.md).**

## Test status

| Item | Test | Result | Notes |
|---|---|---|---|
| Input stage | 12V car input reverse polarity | NOT TESTED | S2Z1 conducts forward into S2F1, which should clear |
| Input stage | Pass-through drop VCAR to PPTRACKER, tracker asleep | NOT TESTED | v1.0 dropped ~0.5V here. Expected ~20 mV, the LTC4412 regulated forward drop |
| Input stage | Pass-through drop VCAR to PPTRACKER at 50 mA and 250 mA | NOT TESTED | Expected ~20 mV; S2Q1 is 15 mΩ so the regulation sets it, not R<sub>DS(on)</sub> |
| Input stage | ISO 7637-2 pulse 2a and 35V load dump ride-through | NOT TESTED | S2Z1 is the tracker's 33V TVS; S2C2 47 µF + S2C6 10 µF + S2C1 on VCAR. Check S2U1 (LTC4412HV) survives the clamp voltage |
| Switchover | Boost enables when the car rail falls below ~10.06V | NOT TESTED | S6U1 with the 6.8M/909k divider |
| Switchover | Boost disables when the car rail returns above ~11V | NOT TESTED | Depends on the cell voltage through S6R38/S6R39, see [Notes](#notes) |
| Switchover | PPTRACKER dip during handover under a forced LTE burst | NOT TESTED | Scope on J2 pin 4; S2C4 82 µF + S2C5 10 µF carry the gap |
| Switchover | Boost stays on through LTE bursts on a part-used cell | NOT TESTED | The v1.0 brownout; with the lockout gone, nothing but the car-sense comparator gates the boost |
| Boost | 9.6V output at S4C14/S4C15 | NOT TESTED | 1.202V x (1 + 909k/130k) = 9.61V; ~9V at J2 after S2D2 |
| Boost | Output current at a 2.5V cell | NOT TESTED | Burst Mode limits to ~190 mA at 2.5V in, ~300 mA at 3V in (datasheet curves) |
| Boost | Bode plot and load step | NOT TESTED | Compensation is the datasheet 2xAA to 12V example, not tuned for this operating point |
| Cell | Reversed cell is harmless | NOT TESTED | S3U1 blocks, VBAT sits at 0V, no backup |
| Cell | No current ever flows into the cell | NOT TESTED | Ammeter in series with the cell with the car present and during handover |
| Wake pulse | IGN pulse at boost start, car ignition wire connected and off | NOT TESTED | Failed on v1.0. Expected ~12V peak, above 8V for ~0.4 s, at J2 pin 5, with S1D1 blocking the car pulldown |
| Wake pulse | Car ignition reaches the tracker | NOT TESTED | J2 pin 5 should be one S1B drop below J1 pin 5 with the key on |
| Wake pulse | Sleeping tracker wakes and raises `backup power` | NOT TESTED | Needs firmware with `CONFIG_APP_BACKUP_SUPPLY=y` |
| Board | Idle draw from the cell, tracker asleep | NOT TESTED | Expected ~280 µA at a 2.9V cell, a few µA less than v1.0 without the lockout |
| Board | Parked drain from the car with the cell fitted | NOT TESTED | Expected ~15 µA (LTC4412HV ~13 µA + ~1.6 µA sense divider) on top of the tracker's own draw |
| Enclosure | Board and cell fit, lid clearance over the cell | NOT TESTED | 1.9 mm above the cell by the datasheet, see [enclosure/](enclosure/) |

## Features

 - Inline between the car harness and the tracker; CAN/K-line pass straight
   through, ignition through S1D1
 - ~15 µA quiescent draw from the car in pass-through (untested): ~13 µA
   LTC4412HV plus the ~1.6 µA sense divider
 - Same input protection parts as the tracker: 2A time-lag fuse, 33V TVS
   sized to ride out suppressed load dump
 - Reverse polarity protection
 - Ideal diode pass-through (LTC4412HV + P-channel FET) with a ~20 mV drop
   down to sleep current
 - Synchronous boost (LTC3122) with true output disconnect: the backup rail
   is 0V while the car is present, so the cell is only ever loaded during a
   cut
 - Nanopower comparator switchover (TLV3012, 2.8 µA) running straight from
   the cell: takes over below ~10.06V on the car rail
 - No cell lockout: the boost runs the cell until it can't. It's a
   consumable primary, so there is nothing to protect
 - Ignition wake pulse: a cut wakes a sleeping tracker immediately instead of
   at its next timed wake, and the tracker reports the cut
 - Estimated runtime on a 1500 mAh CR123A: ~200 days idle, ~58 days
   reporting hourly, ~19 days reporting every 15 minutes
 - 3D-printable two-part enclosure with the cell accessible under the lid

## Why a primary cell

A non-rechargeable cell rather than a rechargeable pack, for three reasons:

- No rechargeable 18650-format cell is rated for storage in a sun-parked car.
  The binding limit is storage temperature (+45 °C at best for Li-ion and LFP;
  +20 °C beyond three months for LTO) and a parked car reaches ~70 °C cabin
  air. A CR123A is rated to +60/+70 °C
- Cycle life is not worth paying for. The backup cycles a handful of times a
  year
- A primary turns silent ageing into an event. The boost regulates its output,
  so the tracker cannot see cell voltage - a rechargeable's calendar fade would
  be invisible until a real theft tested it. The only thing that consumes a
  primary is a power cut the tracker already alerts on, so *"did it get
  used?"* is answered in the server's alert log

The cell is a consumable. A `backup power` alert that runs for a long time
means the cell needs replacing, since it does not recover. Taking the cell
out is the storage mode.

### Ignition wake pulse

A sleeping tracker has three wake sources: its timer, the accelerometer and
ignition-present. A power cut touches none of them, so on its own it would be
found at the next timed wake. The module therefore fakes ignition for a
moment when it takes over.

The tracker's wake is level-triggered and the firmware latches it, so the
pulse only has to trip the interrupt. On an ignition wake the firmware reads
the rail first: in the backup band it is the module's pulse, so the unit
reports at once with the `backup power` alert and goes back to sleep.

The car holds its ignition wire at ground when the key is off, which sank
the pulse on v1.0. S1D1 sits in series between the car's ignition (J1 pin 5)
and the tracker's (J2 pin 5) so the pulse only drives the tracker's input.
The cost is one silicon diode drop on the ignition signal the tracker sees.

Limits: a second cut within the ~40 s VBOOST decay gives no pulse and falls
back to the timed wake.

## Board configuration

### Connectors

Both connectors are the tracker's Molex Micro-Fit 3.0 2x3 (43045-0600) with
the v3.4 pinout. J1 is the car harness, J2 goes to the tracker.

| Pin | J1 (car) | J2 (tracker) | Notes |
|-----|---|---|---|
| 1 | SPARE | SPARE | Unused by v3.4, not connected on this board |
| 2 | GND | GND | |
| 3 | CAN\_H / K | CAN\_H / K | Passed straight through |
| 4 | +12V | +12V (PPTRACKER) | Car through the ideal diode, or ~9V from the boost on backup |
| 5 | IGN | IGN | Through S1D1 (one diode drop); the wake pulse is injected on the J2 side |
| 6 | CAN\_L / L | CAN\_L / L | Passed straight through |

### Firmware

The tracker needs `CONFIG_APP_BACKUP_SUPPLY=y`. With it, a supply between
`CONFIG_APP_BACKUP_MIN_MV` (8500) and `CONFIG_APP_BACKUP_MAX_MV` (9700) with
the ignition off is treated as backup power rather than a flat car battery:
timed reports keep going, the 11.8V power-off and 12.0V sleep-safety rules
are bypassed, a `backup power` alert is raised once and a `car power
restored` alert when the rail comes back. Without the module a car battery in
that band is flat, so leave it off on trackers that do not have one.

### Cell

The board carries a Keystone 1051 CR123A holder and nothing else as a cell
input. Fit a CR123A from one of the three big brands (Energizer 123 /
EL123AP, Panasonic CR123A, Duracell DL123A): all are high-rate Li-MnO2 cells,
1500-1550 mAh, rated for the ~130 mA typical / ~250 mA worst-case bursts the
boost draws. Mark polarity on the silk and the lid; a reversed cell is
harmless but gives no backup.

Other primary chemistries (a 4.1V Tadiran TLM for installs above 60 °C, a
C-size Li-SOCl2 for long runtime) are **not** stuffing options on this board:
neither fits the CR123A holder, a 4.1V cell needs the comparator's supply
range and the boost input checked, and Li-SOCl2 wants a depassivation
bleed. Either is a sheet 3 change.

## Notes

 - **Nothing may ever charge the cell.** Do not add any path from VBOOST,
   PPTRACKER or VCAR to VBAT. If the LM66100 is ever replaced, the
   replacement must block reverse current
 - The LTC3122's exposed pad is PGND. Solder it
 - The tracker's flex-crack rule applies to every 1210 ceramic on this board
   (S2C5, S2C6, S4C14, S4C15): soft-termination parts only, kept away from
   board edges and mounting holes
 - S4R19 (boost FB top) is the one anti-sulfur resistor that matters: open, the
   LTC3122 runs to its ceiling, the same failure as the tracker buck's top
   resistor. S6R33 uses the same part for convenience. Everything else is
   plain thick film; use a non-sulfur foam under the lid over the cell
 - S2D2 and S5D3 must stay glass-passivated silicon (S1B), not Schottky. The
   wake pulse depends on VBOOST resting near 0V while the car is present, and
   the only thing holding it there against S2D2's reverse leakage is the 1.04M
   FB divider; a Schottky's leakage on a hot day parks VBOOST at a few volts
   and shortens the pulse
 - S6R32 is 0603 rather than 0402 for its 75V rating against load dump; it
   sits directly on the car rail
 - Car-sense return threshold: while on backup S6U1's output sits at the cell
   voltage, so IN+ = 1.242V + (VBAT - 1.242V) x 47k / 1.047M ≈ 1.30-1.33V
   for a 2.5-3.2V cell, and the rail has to come back above ~11.0-11.3V
   before the boost releases. That is below a resting car battery, but the
   threshold moves with the cell voltage - measure it before relying on it
 - The comparator, boost and wake-pulse switch all run from VBAT.
   With no cell fitted nothing on sheets 3-6 is powered, the LTC3122 has no
   VIN, and the board is a straight pass-through with an ideal diode in it
 - The `endpoint_off_grid` ERC warnings are cosmetic
 - S1J1/S1J2 pin 3 and pin 6 pass CAN/K-line straight through with no
   protection on this board; the tracker's own protection covers them
 - S2Z1's 33V standoff (36.7V minimum breakdown) is chosen to ride out a
   suppressed 35V load dump without conducting, the same reasoning as the
   tracker's input stage. A lower TVS would conduct for the whole 400 ms event
   and fail short. Do not lower it
 - Put the cell axis across the car (left-right) so road
   shock and braking act across the contacts rather than along them, and have
   the enclosure lid bear on the cell through a foam pad
 - Indicated voltages and tolerances are the minimum. Several of the
   "example" links are the tracker's parts, which may be tighter tolerance or
   higher voltage than the indicated minimum spec

## Bill of materials

| Item | Description | Specification | Example | Notes |
|---|---|---|---|---|
| S1J1 | Car harness connector | Molex Micro-Fit 3.0 2x03 43045-0600 | [43045-0600](https://uk.farnell.com/molex/43045-0600/conn-r-a-pcb-hdr-6pos-2row-3mm/dp/1012252) | |
| S1J2 | Tracker harness connector | Molex Micro-Fit 3.0 2x03 43045-0600 | [43045-0600](https://uk.farnell.com/molex/43045-0600/conn-r-a-pcb-hdr-6pos-2row-3mm/dp/1012252) | |
| S1D1 | Ignition isolation diode | S1B SMA, 100V 1A silicon | [S1B-13-F](https://www.ebay.co.uk/itm/178539943449) | IGN\_CAR to IGN; stops the car pulling the wake pulse down |
| S2F1 | 2A fuse, car input | 1206 2A time-lag | [0407002.WRA](https://www.ebay.co.uk/itm/178539955750) | Time-lag, same as tracker S2F1/S2F2 |
| S2Z1 | 33V TVS diode | PTVS33VS1UTR,115 SOD-123W | [PTVS33VS1UTR,115](https://www.ebay.co.uk/itm/178539916580) | Do not lower the standoff, see [Notes](#notes) |
| S2U1 | Ideal diode controller | LTC4412HV TSOT-23-6 | LTC4412HVIS6#PBF | ~13 µA Iq; replaces v1.0's LM74610 |
| S2Q1 | Ideal diode MOSFET | SQD50P06-15L DPAK, P-channel, -60V, 15 mΩ, AEC-Q101 | SQD50P06-15L_GE3 | |
| S2D2 | OR-ing diode from VBOOST | S1B SMA, 100V 1A silicon | [S1B-13-F](https://www.ebay.co.uk/itm/178539943449) | Silicon, not Schottky |
| S2C1 | 100nF capacitor | 0402 >= 50V 10% X7R | [GRM155R71H104KE14D](https://uk.farnell.com/murata/grm155r71h104ke14d/cap-0-1-f-50v-10-x7r-0402/dp/2611912) | |
| S2C2 | 47uF hybrid polymer electrolytic, VCAR | 63V SMD, 8 x 10.2 mm | EEH-ZC1J470P | |
| S2C4 | 82uF hybrid polymer electrolytic, PPTRACKER | 63V SMD, 10 x 10.5 mm | HHXC630ARA820MJA0G | |
| S2C5 | 10uF capacitor, PPTRACKER | 1210 >= 50V 10% X7R SOFT TERMINATION | [MCJCU32MLB7106KPPDT1](https://uk.farnell.com/taiyo-yuden/mcjcu32mlb7106kppdt1/capacitor-mlcc-10uf-50v-x7r-1210/dp/4666637) | Flex-crack rule |
| S2C6 | 10uF capacitor, VCAR | 1210 >= 50V 10% X7R SOFT TERMINATION | [MCJCU32MLB7106KPPDT1](https://uk.farnell.com/taiyo-yuden/mcjcu32mlb7106kppdt1/capacitor-mlcc-10uf-50v-x7r-1210/dp/4666637) | Flex-crack rule |
| S3BT1 | CR123A holder | Keystone 1051, through-hole | [1051](https://uk.farnell.com/keystone/1051/battery-holder-cr123a-through/dp/3759162) | Pin 1 is + |
| S3F1 | 2A fuse, cell | 1206 2A time-lag | [0407002.WRA](https://www.ebay.co.uk/itm/178539955750) | Not a PTC: the 2A 0ZCJ part is only rated 6V |
| S3U1 | Ideal diode | LM66100 SC70-6 | [LM66100DCKR](https://www.ebay.co.uk/itm/178539979903) | Same part as tracker S11U1 |
| S3C1 | 2.2uF capacitor | 0603 >= 25V 10% X7R | [GRM188Z71E225KE43D](https://uk.farnell.com/murata/grm188z71e225ke43d/cap-mlcc-2-2uf-x7r-25v-0603/dp/4335731) | |
| S4U5 | Boost converter | LTC3122EMSE MSOP-12-EP | [LTC3122EMSE#PBF](https://www.digikey.co.uk/en/products/detail/analog-devices-inc/LTC3122EMSE-PBF/3516527) | Solder the exposed pad, it is PGND |
| S4L1 | Inductor | XFL4020-222ME 2.2uH | [XFL4020-222MEC](https://uk.farnell.com/coilcraft/xfl4020-222mec/inductor-2-2uh-8a-20-pwr-38mhz/dp/2289216) | Same part as tracker S6L1 |
| S4C7 | 47uF input capacitor | 1210 >= 10V 20% X7R | [CL32B476MPJNNNE](https://uk.farnell.com/semco/cl32b476mpjnnne/cap-mlcc-47uf-10vdc-x7r-1210/dp/5109745) | Same part as tracker S11C1 |
| S4C8 | 47uF input capacitor | 1210 >= 10V 20% X7R | [CL32B476MPJNNNE](https://uk.farnell.com/semco/cl32b476mpjnnne/cap-mlcc-47uf-10vdc-x7r-1210/dp/5109745) | |
| S4C9 | 100nF CAP pin capacitor | 0402 >= 50V 10% X7R | [GRM155R71H104KE14D](https://uk.farnell.com/murata/grm155r71h104ke14d/cap-0-1-f-50v-10-x7r-0402/dp/2611912) | CAP to VOUT |
| S4C11 | 560pF compensation capacitor | 0402 >= 50V 5% C0G/NP0 | Any 0402 560pF C0G | |
| S4C12 | 10pF compensation capacitor | 0402 >= 50V 5% C0G/NP0 | [GRM1555C1H100JA01D](https://uk.farnell.com/murata/grm1555c1h100ja01d/cap-mlcc-10pf-c0g-np0-50v-0402/dp/4326648) | |
| S4C13 | 4.7uF VCC capacitor | 0805 >= 50V 10% X7R | [GRM21BZ71H475KE15K](https://uk.farnell.com/murata/grm21bz71h475ke15k/cap-4-7uf-50v-mlcc-0805/dp/3582887) | |
| S4C14 | 10uF output capacitor | 1210 >= 50V 10% X7R SOFT TERMINATION | [MCJCU32MLB7106KPPDT1](https://uk.farnell.com/taiyo-yuden/mcjcu32mlb7106kppdt1/capacitor-mlcc-10uf-50v-x7r-1210/dp/4666637) | 50V rating keeps ~9 µF at 9.6V |
| S4C15 | 10uF output capacitor | 1210 >= 50V 10% X7R SOFT TERMINATION | [MCJCU32MLB7106KPPDT1](https://uk.farnell.com/taiyo-yuden/mcjcu32mlb7106kppdt1/capacitor-mlcc-10uf-50v-x7r-1210/dp/4666637) | |
| S4R14 | Oscillator frequency resistor | 0402 57.6K 1% | Any 0402 57.6K 1% | 57.6K == 1MHz |
| S4R18 | Compensation resistor | 0402 200K 1% | Any 0402 200K 1% | |
| S4R19 | FB divider top | 0402 909K 1% ANTI-SULFUR AEC-Q200 | [AF0402FR-07909KL](https://www.digikey.co.uk/en/products/detail/yageo/AF0402FR-07909KL/16992580) | VOUT == 1.202V x (1 + S4R19/S4R20) == 9.61V, keep 1%, anti-sulfur required |
| S4R20 | FB divider bottom | 0402 130K 1% | Any 0402 130K 1% | Keep 1% |
| S5C17 | Wake pulse flying capacitor | 0805 >= 50V 10% X7R | [GRM21BZ71H475KE15K](https://uk.farnell.com/murata/grm21bz71h475ke15k/cap-4-7uf-50v-mlcc-0805/dp/3582887) | 50V part so it keeps ~4 µF at 12V bias |
| S5Q6 | Wake pulse switch | 2N7002 SOT-23 | [2N7002](https://uk.farnell.com/multicomp-pro/2n7002/mosfet-n-ch-60v-0-115a-sot-23/dp/4295174) | Any vendor |
| S5Q7 | Wake pulse high-side PNP | BC856B SOT-23 | [BC856BLT1G](https://www.ebay.co.uk/itm/178539823265) | |
| S5D3 | Wake pulse isolation diode | S1B SMA, 100V 1A silicon | [S1B-13-F](https://www.ebay.co.uk/itm/178539943449) | Silicon, not Schottky |
| S5R21 | Wake pulse series resistor | 0402 10K 5% | [CRCW040210K0FKED](https://uk.farnell.com/vishay/crcw040210k0fked/res-10k-1-0-063w-0402-thick-film/dp/1469669) | |
| S5R22 | Wake capacitor charge resistor | 0402 1M 1% | [ERJ2RKF1004X](https://uk.farnell.com/panasonic/erj2rkf1004x/res-1m-1-0-1w-0402-thick-film/dp/2302957) | |
| S5R24 | Q7 base drive resistor | 0402 1M 1% | [ERJ2RKF1004X](https://uk.farnell.com/panasonic/erj2rkf1004x/res-1m-1-0-1w-0402-thick-film/dp/2302957) | |
| S5R25 | Q7 base-emitter hold-off | 0402 1M 1% | [ERJ2RKF1004X](https://uk.farnell.com/panasonic/erj2rkf1004x/res-1m-1-0-1w-0402-thick-film/dp/2302957) | |
| S6U1 | Car-rail sense comparator | TLV3012 SOT-23-6 | [TLV3012AIDBVR](https://www.digikey.co.uk/en/products/detail/texas-instruments/TLV3012AIDBVR/1678203) | 1.242V reference, 2.8 µA |
| S6R32 | Car-rail divider top | 0603 6.8M 1% | Any 0603 6.8M 1% 75V | 0603 for the 75V rating |
| S6R33 | Car-rail divider bottom | 0402 909K 1% ANTI-SULFUR AEC-Q200 | [AF0402FR-07909KL](https://www.digikey.co.uk/en/products/detail/yageo/AF0402FR-07909KL/16992580) | Same part as S4R19; anti-sulfur not required here |
| S6R38 | Car-sense hysteresis | 0402 47K 5% | [ERJ2RKF4702X](https://uk.farnell.com/panasonic/erj2rkf4702x/res-47k-1-0-1w-0402-thick-film/dp/2302806) | |
| S6R39 | Car-sense hysteresis feedback | 0402 1M 1% | [ERJ2RKF1004X](https://uk.farnell.com/panasonic/erj2rkf1004x/res-1m-1-0-1w-0402-thick-film/dp/2302957) | |
| S6C1 | IN- filter capacitor | 0402 >= 50V 5% C0G/NP0 | [0402N101J500CT](https://uk.farnell.com/multicomp-pro/0402n101j500ct/cap-100pf-50v-5-c0g-np0-0402/dp/2496792) | |
| S6C2 | Comparator decoupling | 0402 >= 50V 10% X7R | [GRM155R71H104KE14D](https://uk.farnell.com/murata/grm155r71h104ke14d/cap-0-1-f-50v-10-x7r-0402/dp/2611912) | |
| - | CR123A cell | Li-MnO2 3.0V 1500-1550 mAh, branded | Energizer EL123AP / Panasonic CR123A / Duracell DL123A | Consumable; buy from a distributor |

## Parts list

Aggregated from the bill of materials above. Quantities are per board.

| Item | Quantity | Specification | Example | Notes |
|---|---|---|---|---|
| Molex Micro-Fit 3.0 2x03 PCB connector | 2 | 43045-0600 | [43045-0600](https://uk.farnell.com/molex/43045-0600/conn-r-a-pcb-hdr-6pos-2row-3mm/dp/1012252) | |
| CR123A holder | 1 | Keystone 1051 | [1051](https://uk.farnell.com/keystone/1051/battery-holder-cr123a-through/dp/3759162) | |
| 2A fuse | 2 | 1206 2A time-lag | [0407002.WRA](https://www.ebay.co.uk/itm/178539955750) | 1x car input, 1x cell |
| 33V TVS diode | 1 | PTVS33VS1UTR,115 SOD-123W | [PTVS33VS1UTR,115](https://www.ebay.co.uk/itm/178539916580) | |
| S1B rectifier | 3 | SMA 100V 1A silicon | [S1B-13-F](https://www.ebay.co.uk/itm/178539943449) | |
| Ideal diode controller | 1 | LTC4412HV TSOT-23-6 | LTC4412HVIS6#PBF | |
| P-channel MOSFET, DPAK | 1 | SQD50P06-15L -60V 15 mΩ | SQD50P06-15L_GE3 | |
| Ideal diode | 1 | LM66100 SC70-6 | [LM66100DCKR](https://www.ebay.co.uk/itm/178539979903) | |
| Boost converter | 1 | LTC3122EMSE MSOP-12-EP | [LTC3122EMSE#PBF](https://www.digikey.co.uk/en/products/detail/analog-devices-inc/LTC3122EMSE-PBF/3516527) | |
| Nanopower comparator | 1 | TLV3012 SOT-23-6 | [TLV3012AIDBVR](https://www.digikey.co.uk/en/products/detail/texas-instruments/TLV3012AIDBVR/1678203) | |
| Inductor | 1 | XFL4020-222ME 2.2uH | [XFL4020-222MEC](https://uk.farnell.com/coilcraft/xfl4020-222mec/inductor-2-2uh-8a-20-pwr-38mhz/dp/2289216) | |
| 2N7002 MOSFET | 1 | SOT-23 | [2N7002](https://uk.farnell.com/multicomp-pro/2n7002/mosfet-n-ch-60v-0-115a-sot-23/dp/4295174) | |
| PNP transistor | 1 | BC856B SOT-23 | [BC856BLT1G](https://www.ebay.co.uk/itm/178539823265) | |
| 47uF 63V hybrid polymer electrolytic | 1 | 8 x 10.2 mm SMD | EEH-ZC1J470P | |
| 82uF 63V hybrid polymer electrolytic | 1 | 10 x 10.5 mm SMD | HHXC630ARA820MJA0G | |
| 10uF 1210 soft-termination capacitor | 4 | 1210 >= 50V 10% X7R SOFT TERMINATION | [MCJCU32MLB7106KPPDT1](https://uk.farnell.com/taiyo-yuden/mcjcu32mlb7106kppdt1/capacitor-mlcc-10uf-50v-x7r-1210/dp/4666637) | |
| 47uF 1210 capacitor | 2 | 1210 >= 10V 20% X7R | [CL32B476MPJNNNE](https://uk.farnell.com/semco/cl32b476mpjnnne/cap-mlcc-47uf-10vdc-x7r-1210/dp/5109745) | |
| 4.7uF 0805 capacitor | 2 | 0805 >= 50V 10% X7R | [GRM21BZ71H475KE15K](https://uk.farnell.com/murata/grm21bz71h475ke15k/cap-4-7uf-50v-mlcc-0805/dp/3582887) | |
| 2.2uF 0603 capacitor | 1 | 0603 >= 25V 10% X7R | [GRM188Z71E225KE43D](https://uk.farnell.com/murata/grm188z71e225ke43d/cap-mlcc-2-2uf-x7r-25v-0603/dp/4335731) | |
| 100nF 0402 capacitor | 3 | 0402 >= 50V 10% X7R | [GRM155R71H104KE14D](https://uk.farnell.com/murata/grm155r71h104ke14d/cap-0-1-f-50v-10-x7r-0402/dp/2611912) | |
| 560pF 0402 capacitor | 1 | 0402 >= 50V 5% C0G/NP0 | Any 0402 560pF C0G | |
| 100pF 0402 capacitor | 1 | 0402 >= 50V 5% C0G/NP0 | [0402N101J500CT](https://uk.farnell.com/multicomp-pro/0402n101j500ct/cap-100pf-50v-5-c0g-np0-0402/dp/2496792) | |
| 10pF 0402 capacitor | 1 | 0402 >= 50V 5% C0G/NP0 | [GRM1555C1H100JA01D](https://uk.farnell.com/murata/grm1555c1h100ja01d/cap-mlcc-10pf-c0g-np0-50v-0402/dp/4326648) | |
| 909K 0402 anti-sulfur resistor | 2 | 0402 909K 1% ANTI-SULFUR AEC-Q200 | [AF0402FR-07909KL](https://www.digikey.co.uk/en/products/detail/yageo/AF0402FR-07909KL/16992580) | S4R19 (required anti-sulfur), S6R33 |
| 1M 0402 resistor | 4 | 0402 1M 1% | [ERJ2RKF1004X](https://uk.farnell.com/panasonic/erj2rkf1004x/res-1m-1-0-1w-0402-thick-film/dp/2302957) | |
| 130K 0402 resistor | 1 | 0402 130K 1% | Any 0402 130K 1% | |
| 200K 0402 resistor | 1 | 0402 200K 1% | Any 0402 200K 1% | |
| 57.6K 0402 resistor | 1 | 0402 57.6K 1% | Any 0402 57.6K 1% | |
| 47K 0402 resistor | 1 | 0402 47K 5% | [ERJ2RKF4702X](https://uk.farnell.com/panasonic/erj2rkf4702x/res-47k-1-0-1w-0402-thick-film/dp/2302806) | |
| 10K 0402 resistor | 1 | 0402 10K 5% | [CRCW040210K0FKED](https://uk.farnell.com/vishay/crcw040210k0fked/res-10k-1-0-063w-0402-thick-film/dp/1469669) | |
| 6.8M 0603 resistor | 1 | 0603 6.8M 1% 75V | Any 0603 6.8M 1% 75V | |
| CR123A cell | 1 | Li-MnO2 3.0V, branded | Energizer EL123AP / Panasonic CR123A / Duracell DL123A | Consumable |
| M2 heat-set insert | 4 | Ø3.2 hole, 4.6 mm | - | Enclosure |
| M2 x 12 mm screw | 4 | - | - | Enclosure; 12 mm, not the tracker enclosure's 10 mm |

## Enclosure

A 3D-printable two-part enclosure is in [enclosure/](enclosure/): 68.9 x
42.0 x 31.0 mm outer, same construction as the v3.3 tracker enclosure (flat
butt joint, M2 heat-set inserts in the top, screws in from underneath). The
cell is accessible with the top removed. Print in PETG or ABS - PLA softens
around 60 °C, which a parked car reaches. Unprinted and unvalidated; see its
[README](enclosure/README.md).

## Images

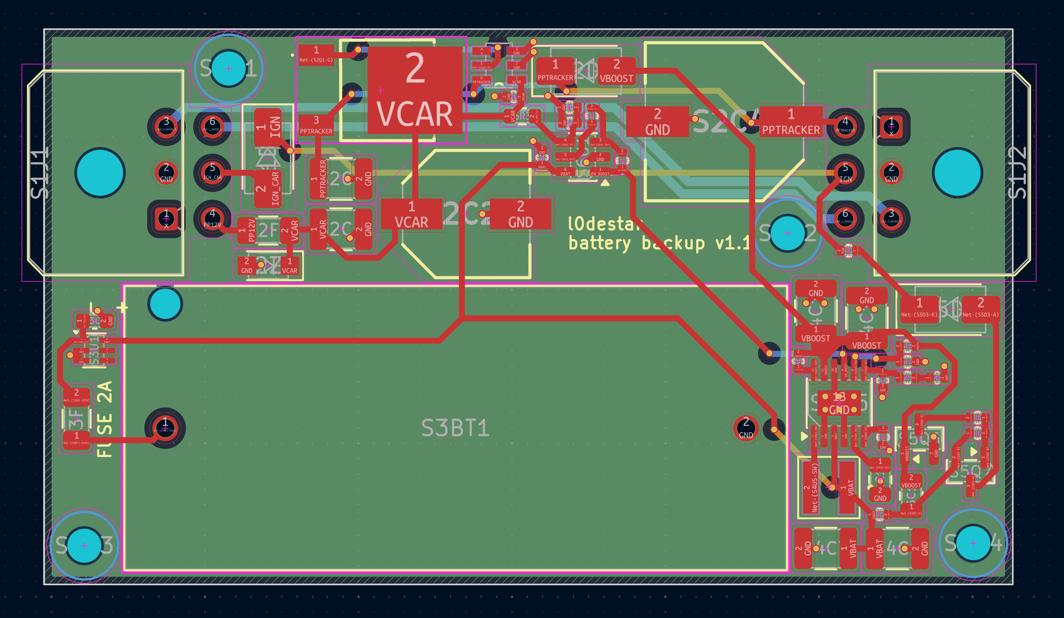
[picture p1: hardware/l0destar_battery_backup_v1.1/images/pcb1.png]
l0destar board

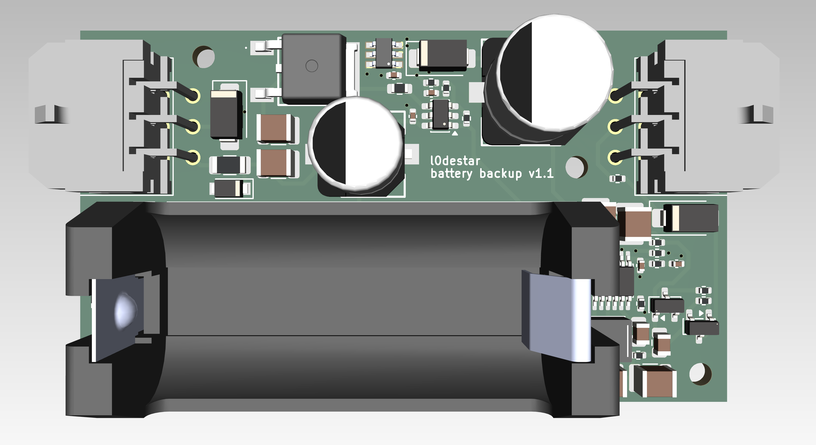
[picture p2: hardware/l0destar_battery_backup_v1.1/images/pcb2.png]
l0destar board

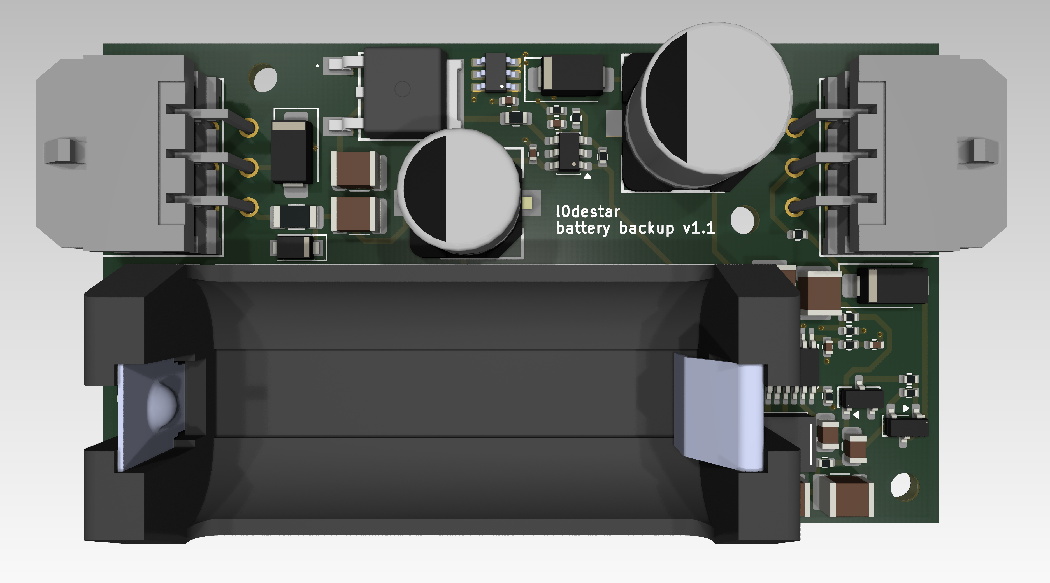
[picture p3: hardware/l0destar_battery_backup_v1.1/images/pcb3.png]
l0destar board


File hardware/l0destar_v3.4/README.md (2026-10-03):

# l0destar v3.4

## Overview

**NOTE: THIS HAS NOT BEEN INDEPENDENTLY TESTED, USE AT YOUR OWN RISK**

- This is a prototype l0destar vehicle tracker PCB designed to be
  hand-solderable (hot air required)
- It makes use of the [Makerdiary nRF9151 Connect Kit](https://makerdiary.com/products/nrf9151-connectkit) to provide the LTE and GPS
functions
- Component vias are dogleg-routed deliberately in order to keep the PCB costs
as low as possible
- The RF trace width is calculated using a standard 4-layer stackup at JLCPCB,
  different fabrication processes may require adjustment

## Disclaimer

This is a prototype, not a product. Nothing here is validated or certified,
the parts lists are examples rather than a verified BOM, and any test results
recorded below are my own unverified bench observations - repeat the testing
yourself rather than taking them on trust.

**Before building or installing anything from this repository, read the
[full disclaimer](../../DISCLAIMER.md).**

## New features

- Fixed the accelerometer symbol: ASM330LHHXTR pins 10 and 11 (NC) were
  grounded on v3.0-v3.3, which stopped the part from ever entering its
  low-power state. Sleep current on a reworked v3.2 board fell from ~140.8 µA
  to ~35.5 µA at 12V.
- The buck enable divider added in v3.3 is now an optional extra, DNP by
  default. S6R4 is a 0R jumper by default, so the expected sleep current is
  ~35.5 µA at 12V; fitting the divider adds around ~9 µA.
- Added test points for easier assembly/testing
- Slightly increased the size of the holes for the 2-pin power connector

Carried over from v3.3:

- Fixed L-line defect that could brick earlier boards if L_SEND was
  used while the external L wire had been shorted to 12V.
- Added L-line sensing capability to detect 12V short faults.
- Buck converter can optionally be tuned to shut off cleanly below inadequate
  supply voltage and turn on again only when the supply has risen significantly
  above the cutoff threshold (to avoid flapping states). Optional in v3.4, see
  [Optional: buck enable divider](#optional-buck-enable-divider-s6r4s6r5s6r6).

See below for a full change summary.

## Fixed defects

### Accelerometer never sleeps (NC pins grounded)

Present in v3.0 - v3.3. The ASM330LHHXTR symbol had pins 10 and 11, which
the datasheet marks NC, as hidden pins stacked on the GND pin, so the layout
tied both pads to the ground pour. With those pins grounded the part never
enters its low-power state and keeps drawing current the whole time the board
is asleep. Fixed here by making pins 10 and 11 proper no-connect pins in the
symbol; the pads are unconnected in the layout.

Tested on a v3.2 board by scraping pads 10 and 11 off the board under S8U1:
sleep current dropped from ~140.8 µA to ~35.5 µA at 12V. The same rework
applies to any existing v3.0 - v3.3 board.

### L line pull-down can be destroyed by a short to battery

Present in v3.0 - v3.2 and described in full in the
[v3.2 README](../l0destar_v3.2/README.md#known-defects). Fixed in v3.3 by S10U2
(AL5809-90) limiting the pulldown to 90 mA, with S10R7 limiting gate-fault
current into the nRF and S10D5/S10R8 adding fault detection on L\_SENSE.

### Suboptimal RF tuning

A VNA sweep of the v3.1 GNSS feed showed about 1.4 dB of insertion loss,
caused by shunt capacitance from the through-hole SMA centre pin against
the In.1/In.2 ground planes. v3.3 modifies the SMA footprint to remove the
centre pin's inner-layer pads and add a 4 mm copper keepout on In.1 and
In.2, bringing the launch closer to 50 Ω. The trace widths on both RF
feeds have also been recalculated for the JLC04161H-7628 stack-up.

## Test status

| Item | Test | Result | Notes |
|---|---|---|---|
| Input stage | 12V input reverse polarity | PASSED | |
| Input stage | 12V ignition input reverse polarity | PASSED | |
| INA238 | Voltage reading function | PASSED | |
| Ignition presence | Ignition sense 3.3v signal | PASSED | |
| LT8609 | 4.2V output | PASSED | |
| LT8609 | UVLO thresholds | PASSED | |
| MCU OVP | 4.2V passes through at nominal voltage | PASSED | S11Q1 on, S12TP2 ≈ the buck output at S6C5 |
| MCU OVP | Cuts off when the buck output (S6C5) is driven above ~5V | PASSED | Trip ≈ 4.95V, release ≈ 4.80V (calculated, see below) |
| MCU OVP | Scope trigger on VBAT rail, should never peak above abs max (~5.5V) during overvoltage condition | PASSED | |
| GPS auxiliary 3.3V rail | Switches on enable signal | PASSED | |
| CAN auxiliary 3.3V rail | Switches on CAN-enable signal | PASSED | |
| K-line auxiliary 3.3V rail | Switches on K-enable signal | PASSED | |
| K-line auxiliary 12V rail | Switches on K-enable signal | PASSED | |
| Accelerometer | Operates while awake | PASSED | |
| Accelerometer | Wake on motion | PASSED | |
| GPS antenna bias tee | Obtains GPS signal | PASSED | |
| K-wire | K wire connectivity | PASSED | |
| K-wire | L-line pulldown | PASSED | |
| K-wire | L-line external short to 12V while L\_SEND high | PASSED | Added to cover the L-line defect in earlier boards |
| K-wire | L-line sensing via L_SENSE | PASSED | |
| CAN | Connectivity | PASSED | |
| CAN standby via XSTBY signal | Low standby current | PASSED | |
| Board | Quiescent current | 35 µA | Fitting the optional enable divider adds around ~9 µA |

## Features

 - 12V live and 12V ignition inputs with TVS and reverse polarity protection
 - Enhanced input protection sized for pulse 2a at the ISO 7637-2:2011 maximum
 - Onboard 2A fusing
 - Ignition presence sensing
 - INA238 voltage reading
 - High efficiency buck converter
 - Auxiliary 3.3V rail for the GPS antenna bias tee
 - ASM330LHHXTR 6-axis IMU gyro/accelerometer
 - USB-C can be connected and disconnected for programming without any power
   disruption
 - Optional CAN interface
 - Optional K-wire (ISO 14230-1 K-line) interface with L and K connections for
   full functionality - the wire carries KWP2000 (ISO 14230-4), the older
   ISO 9141-2, and manufacturer-specific pre-OBD protocols such as VAG KW1281
 - CAN/K-wire switchable via jumper pads
 - Auxiliary rail sensing/fault detection
 - MCU over-voltage protection on the 4.2V rail with fault-injection test point
 - I2C bus filtering against LTE TX bursts

## Changes from v3.3

- Fixed the ASM330LHHXTR accelerometer symbol. Pins 10 and 11 are NC on the
  datasheet but the symbol had them as hidden pins on the GND pin, so they
  were grounded in the layout on every board from v3.0 to v3.3. This kept the
  accelerometer from ever entering its low-power state. The pins are now
  no-connect and the pads are left unconnected. Measured on a v3.2 board with
  the two pads scraped off: sleep current went from ~140.8 µA to ~35.5 µA at
  12V.
- Made the LT8609 enable divider (S6R4/S6R5/S6R6, added in v3.3) an optional
  extra, DNP by default. S6R4 is now fitted as a 0R jumper by default so EN is
  tied straight to VIN and the buck runs whenever the input is present; S6R5
  and S6R6 are DNP. Fitting the divider costs around ~9 µA of sleep current on
  top of the ~35.5 µA baseline, so the default build sits at ~35.5 µA at 12V.
  See [Optional: buck enable divider](#optional-buck-enable-divider-s6r4s6r5s6r6)
  for the fitted values.
- Added test points for easier assembly/testing
- Slightly increased the size of the holes for the 2-pin power connector

## Changes from v3.2

- VNA measured signal attenuation pre-v3.3 boards at -1.4dB which isn't great.
  Suspect it's because the SMA connectors are through-hole. in v3.3 I edited the
  footprint for the SMA and set the centre pins to connect to F.cu and B.cu only
  and put a keepout around them excluding In.1 and In.2.
- Increased width for the LTE RF trace to 0.36mm (was previously 0.292mm,
  incorrect)
- Increased width for the GPS TF trace to 0.306mm (was 0.292mm, incorrect)
- An L-line circuit defect was fixed by adding an AL5809-90 in series on the L
  wire to limit the pulldown current to 90mA in the event of the external L pin
  being shorted to 12V. This part also automatically shuts down blocking the
  current if it exceeds its rated temperature.
- A secondary mitigation for the same defect is S10R7, a 47K resistor in
  series between the L\_SEND GPIO and the 2N7002 gate, backed by S10R9 (1M)
  holding the gate down. If S10Q1 ever fails drain-gate short - the failure
  mode that destroyed the nRF on earlier boards - S10R7 limits the fault
  current reaching the GPIO to ~250 uA at 12V, the same limit as the L\_SENSE
  path.
- Add a sense capability on the L line to safely detect fault conditions. If
  the L wire is shorted to 12V this is safely detected at the L\_SENSE GPIO,
  with current from the external 12V blocked by a 1N4148 (S10D5). If that
  diode ever failed short, S10R8 (47K) bounds the current reaching the GPIO
  to ~250 uA at 12V.
- 3-resistor divider added to the LT8609 enable pin (made optional and DNP by
  default in v3.4). With it fitted the buck won't turn on until
  the supply voltage reaches ~5.6V and will turn off if the supply falls to
  ~4.3V, requiring ~5.6V to turn on again (clear hysteresis here avoids it
  ending up in a continuously flapping state). Worst case over the EN/UV pin
  threshold's specified 0.99-1.11V band the turn-off point stays within
  3.97-4.61V, comfortably above the ~3.4V at which the board browns out under
  peak LTE load. This is to address ISO 16750-2 tests that require clearly
  defined behaviour during low voltage or drop-out events.
- 1uF caps were resized to 0603 - higher voltage ratings available, some of the
  1uF parts were right at the limit of suitability. Now standardised on 2.2uF
  25V 0603.
- Made S11C3 fitted by default, no good reason to have it be DNP by default.
- Made the accelerometer bead fitted by default, same reason. Also switched the
  part number for availability reasons.
- Made S6R2 explictly anti-sulfur, although it doesn't really technically need
  it the part number in the README was already specifying an anti-sulfur part by
  chance and having it be explicitly anti-sulfer matches the other half of the
  divider.
- GPIOs reassigned and some layout tweals in order to allow L_SENSE to be on
  one of the GPIOs that supports SAADC. It needs the SAADC's internal pull-up
  resistor ladder in order to work properly as the diode only conducts when you
  source current into the node.

## Power supply

The Connect Kit can be powered through VBUS which would be much simpler as it
can take 5V, but then you have to disconnect the power before connecting a USB
cable. Same for the Nordic dev board - they both explicitly say not to connect
powered USB and VBUS at the same time. Because the intention is to install this
in a vehicle for testing the pragmatic decision was taken to power it with a
4.2V buck feeding the battery connector. With this power connection we can
connect USB-C at any time to update the firmware without needing to disconnect
power.

## Board configuration

See below for parts required for either CAN bus or K-wire (ISO 14230-1 K-line). Both sets
of components can be populated for future use but only one set can be in use at
any given time.

The table below shows which jumper pads should be connected for each of these
modes. **It's critical that only one system is enabled at the same time, if you
short both CAN and K-line pads at the same time unpredictable behaviour may
occur**

Connect the pads as required by bridging them with solder or placing a 0R
resistor. **Make sure the pads that should be unconnected are not connected.**

| Interface | S5R1 | S5R2 | S5R3 | S5R4 |
|---|---|---|---|---|
| None | OPEN | OPEN | OPEN | OPEN |
| CAN bus | CONNECT | OPEN | CONNECT | OPEN |
| K-line | OPEN | CONNECT | OPEN | CONNECT |

S5R5 is a separate pad on the same sheet: it bridges `PP4V2_UNPROTECTED`
straight to `PP4V2_OVP_PROTECTED`, bypassing the OVP MOSFET S11Q1. Leave it
**OPEN** unless the S11x protection circuit is not populated. Not recommended.

The S5R1-S5R4 pads only route the two vehicle bus lines (S1J1 pin 3 and pin 6)
to one interface or the other. Power rails for CAN and K-line are switched by
separate load switches.

## Notes

 - All caps on the 12V rails must be >= 50V in order to handle transients
 - MCP2518FD with PP3V3\_CAN off - abs max on all I/O is VDD + 0.3V. Firmware
   must drive CAN\_SCK/SDI/CS low or tri-state them before dropping
   CAN\_ENABLE, or the nRF backfeeds the dead rail through the clamp diodes.
   Additionally, CAN\_CS and CAN\_INT have their pull-ups (S9R1, S9R2) on the
   switched rail, so both float when the domain is off - enable the nRF
   internal pulldown on those pins
 - K-line side, now its own domain - K\_ENABLE gates PP3V3\_K and PP12V\_K
   together. Both K\_TX and K\_SLEEP land on the TJA1027T, which is supplied
   from PP12V\_K (VBAT, pin 7), so driving either high with the rail down
   backfeeds it through the transceiver's ESD clamps. K\_TX and K\_RX also
   carry 10K pull-ups (S10R2, S10R1) to PP3V3\_K, which float when that rail
   is down. Firmware must take the TJA1027T to sleep (K\_SLEEP low) and then
   park K\_TX/K\_RX/K\_SLEEP before dropping K\_ENABLE
 - L\_SEND is not on a switched rail, so it is safe to drive at any time. It
   reaches S10Q1's gate through S10R7 (47K series), with the 10K pulldown
   (S10R5) on the GPIO side and S10R9 (1M) holding the gate down directly, so
   the FET stays off while the nRF is in reset or the pin is parked - and even
   if S10R7 opens. S10Q1's drain reaches the L wire through S10U2, an
   AL5809-90 that caps the pulldown at 90 mA and thermally shuts down, so an
   external short to battery can no longer cook the FET. The same node is
   tapped for L\_SENSE through S10D5 (cathode on the L node, blocking the
   vehicle's 12V) and S10R8 (47K)
 - K\_SLEEP has a 100K pulldown (S10R6), so the transceiver stays asleep while
   the nRF is in reset or the pin is parked
 - The OVP stage latches off while the unprotected rail stays above the
   release threshold. If the buck is genuinely faulted it will stay off; to
   clear a transient trip the input power has to drop far enough for the buck
   output to fall below ~4.8V
 - What the trip point has to protect: the 4.2V rail lands on the Connect Kit's
   battery connector (J2, MX1.25-2P), which goes to the **BAT pin of its
   BQ25180 charger** - not to the nRF9151 directly. On the BQ25180 only the IN
   pin is 25V tolerant; BAT and SYS are rated -0.3V to 5.5V absolute maximum.
   With no USB attached the BATFET conducts BAT to SYS, and SYS feeds nRF9151
   VDD through ferrite L4, so an over-voltage reaches the SiP as well - and the
   nRF9151 VDD absolute maximum is also 5.5V (VDD\_GPIO is a separate rail at
   3.9V). So 5.5V is the ceiling on both counts
 - S11R5/S11R6 set the trip point: V\_trip ≈ 2.5V × (1 + S11R5/S11R6) shifted
   slightly by S11R3. Nominal trip is ≈4.95V; worst case over the ATL431B's
   0.5% reference, 1% on S11R5/S11R6 and 5% on S11R3 the window is ≈4.87V to
   5.02V, so it stays clear of the buck's nominal 4.24V plus ripple at the
   bottom and keeps ~0.48V of margin to the 5.5V ceiling at the top. Keep the
   divider at 1% - a 5% pair widens that window at both ends
 - Indicated voltages and tolerances are the minimum, I generally always buy the
   tightest tolerances and highest voltages possible of everything as it's just
   simpler for managing inventory. Because of this, several of the "example"
   links will be to the parts I bought which might be tighter tolerance or
   higher voltage rating than the indicated minimum spec
 - Both L-line GPIO protections work the same way: S10R7 on L\_SEND (against a
   drain-gate short in S10Q1) and S10R8 on L\_SENSE (against S10D5 failing
   short). Each is 47K, bounding the fault current to ~250 uA at 12V, and each
   relies on the nRF9151's internal clamp to hold the voltage. Note that
   Nordic specify only a voltage limit on I/O pins (-0.3V to VDD\_GPIO + 0.3V)
   and publish no clamp or injection current rating; while the clamp conducts
   the pin necessarily sits above that limit, and the current is delivered
   into VDD\_GPIO, which the Connect Kit's TPS63901 cannot sink. 250 uA is
   judged small enough on both counts, but this is a design assumption rather
   than a datasheet-backed guarantee

## Bill of materials - required

| Item | Description | Specification | Example | Notes |
|---|---|---|---|---|
| MCU | MCU and GSM/GPS 40pin board | nRF9151 Connect Kit | [Makerdiary nRF9151 Connect Kit](https://makerdiary.com/products/nrf9151-connectkit) | |
| S1J1 | Molex Micro-fit 3.0 2x03 PCB connector | 43045-0600 | [43045-0600](https://uk.farnell.com/molex/43045-0600/conn-r-a-pcb-hdr-6pos-2row-3mm/dp/1012252) | |
| S1J2 | Makerdiary header 1 | 20-pin 2.54mm header | [20-pin pcb header](https://www.aliexpress.com/item/1005003610333849.html) | |
| S1J3 | Makerdiary header 2 | 20-pin 2.54mm header | [20-pin pcb header](https://www.aliexpress.com/item/1005003610333849.html) | |
| S1R1 | I2C pull-up resistor | 0402 1.8K 1% | [MCMR04X1801FTL](https://uk.farnell.com/multicomp-pro/mcmr04x1801ftl/res-1k8-1-0-0625w-0402-ceramic/dp/2072709) | |
| S1R2 | I2C pull-up resistor | 0402 1.8K 1% | [MCMR04X1801FTL](https://uk.farnell.com/multicomp-pro/mcmr04x1801ftl/res-1k8-1-0-0625w-0402-ceramic/dp/2072709) | |
| S1R3 | 100K pulldown resistor | 0402 100K 5% | [MCPWR02FTEP1003A](https://uk.farnell.com/multicomp-pro/mcpwr02ftep1003a/res-100k-1-thick-film-0402/dp/4538624) | |
| S1R4 | 100K pulldown resistor | 0402 100K 5% | [MCPWR02FTEP1003A](https://uk.farnell.com/multicomp-pro/mcpwr02ftep1003a/res-100k-1-thick-film-0402/dp/4538624) | |
| S1R5 | 100K pulldown resistor | 0402 100K 5% | [MCPWR02FTEP1003A](https://uk.farnell.com/multicomp-pro/mcpwr02ftep1003a/res-100k-1-thick-film-0402/dp/4538624) | |
| S1C1 | 100nF capacitor | 0402 >= 50V 10% X7R | [GRM155R71H104KE14D](https://uk.farnell.com/murata/grm155r71h104ke14d/cap-0-1-f-50v-10-x7r-0402/dp/2611912) | |
| S2F1 | 2A fuse | 1206 2A slow blow | [0407002.WRA](https://www.ebay.co.uk/itm/178539955750) | |
| S2F2 | 2A fuse | 1206 2A slow blow | [0407002.WRA](https://www.ebay.co.uk/itm/178539955750) | |
| S2Q1 | Reverse-polarity MOSFET | SQ2361 SOT-23 | [SQ2361CES-T1_BE3](https://www.ebay.co.uk/itm/178539853850) | |
| S2Q2 | Reverse-polarity MOSFET | SQJ457EP-T1_BE3 | [SQJ457EP-T1-GE3](https://www.ebay.co.uk/itm/178539865485) | |
| S2D1 | 15V Zener diode | BZX84C15 | [BZX84C15](https://uk.farnell.com/multicomp-pro/bzx84c15/zener-diode-0-3w-15v-sot-23/dp/2675186) | |
| S2D2 | 400W TVS diode | PTVS33VS1UTR,115 SOD-123W | [PTVS33VS1UTR,115](https://www.ebay.co.uk/itm/178539916580) | |
| S2D3 | 15V Zener diode | BZX84C15 | [BZX84C15](https://uk.farnell.com/multicomp-pro/bzx84c15/zener-diode-0-3w-15v-sot-23/dp/2675186) | |
| S2D4 | 400W TVS diode | PTVS33VS1UTR,115 SOD-123W | [PTVS33VS1UTR,115](https://www.ebay.co.uk/itm/178539916580) | |
| S2R1 | Pulldown resistor | 0402 1M 5% | [ERJ2RKF1004X](https://uk.farnell.com/panasonic/erj2rkf1004x/res-1m-1-0-1w-0402-thick-film/dp/2302957) | |
| S2R2 | Pulldown resistor | 0402 100K 5% | [MCPWR02FTEP1003A](https://uk.farnell.com/multicomp-pro/mcpwr02ftep1003a/res-100k-1-thick-film-0402/dp/4538624) | |
| S2C1 | 47uF input capacitor | 2220 >= 50V 20% X7R | [CKG57NX7R1H476M500JH](https://uk.farnell.com/tdk/ckg57nx7r1h476m500jh/cap-stacked-47uf-50v-mlcc-2220/dp/3816888) | |
| S2C2 | 47uF input capacitor | 2220 >= 50V 20% X7R | [CKG57NX7R1H476M500JH](https://uk.farnell.com/tdk/ckg57nx7r1h476m500jh/cap-stacked-47uf-50v-mlcc-2220/dp/3816888) | |
| S2C3 | 10uF input capacitor | 1210 >= 50V 10% X7R SOFT TERMINATION | [MCJCU32MLB7106KPPDT1](https://uk.farnell.com/taiyo-yuden/mcjcu32mlb7106kppdt1/capacitor-mlcc-10uf-50v-x7r-1210/dp/4666637) | |
| S3U1 | INA238 voltage read IC | INA238 10-VSSOP | [INA238AIDGSR](https://www.digikey.co.uk/en/products/detail/texas-instruments/INA238AIDGSR/15857213) | |
| S3C1 | 2.2uF capacitor | 0603 >= 25V 10% X7R | [GRM188Z71E225KE43D](https://uk.farnell.com/murata/grm188z71e225ke43d/cap-mlcc-2-2uf-x7r-25v-0603/dp/4335731) | |
| S3C2 | 100nF capacitor | 0402 >= 50V 10% X7R | [GRM155R71H104KE14D](https://uk.farnell.com/murata/grm155r71h104ke14d/cap-0-1-f-50v-10-x7r-0402/dp/2611912) | |
| S4Q1 | Ignition sense MOSFET | 2N7002 SOT-23 | [2N7002](https://uk.farnell.com/multicomp-pro/2n7002/mosfet-n-ch-60v-0-115a-sot-23/dp/4295174) | |
| S4R1 | Ignition sense resistor | 0402 180K 5% | [MCWR04X1803FTL](https://uk.farnell.com/multicomp-pro/mcwr04x1803ftl/res-180k-1-0-0625w-thick-film/dp/2447116) | |
| S4R2 | Ignition sense resistor | 0402 56K 5% | [MCMR04X5602FTL](https://uk.farnell.com/multicomp-pro/mcmr04x5602ftl/res-56k-1-0-0625w-0402-ceramic/dp/2073131) | |
| S4R3 | Ignition sense resistor | 0402 56K 5% | [MCMR04X5602FTL](https://uk.farnell.com/multicomp-pro/mcmr04x5602ftl/res-56k-1-0-0625w-0402-ceramic/dp/2073131) | |
| S4C1 | 100nF capacitor | 0402 >= 50V 10% X7R | [GRM155R71H104KE14D](https://uk.farnell.com/murata/grm155r71h104ke14d/cap-0-1-f-50v-10-x7r-0402/dp/2611912) | |
| S6U1 | Buck converter | LT8609AIMSE MSOP-EP-10 | [LT8609AIMSE#PBF](https://www.ebay.co.uk/itm/178544379670) | |
| S6L1 | Inductor | XFL4020-222ME | [XFL4020-222MEC](https://uk.farnell.com/coilcraft/xfl4020-222mec/inductor-2-2uh-8a-20-pwr-38mhz/dp/2289216) | |
| S6C1 | 100nF capacitor | 0402 >= 50V 10% X7R | [GRM155R71H104KE14D](https://uk.farnell.com/murata/grm155r71h104ke14d/cap-0-1-f-50v-10-x7r-0402/dp/2611912) | |
| S6C2 | 2.2uF capacitor | 0603 >= 25V 10% X7R | [GRM188Z71E225KE43D](https://uk.farnell.com/murata/grm188z71e225ke43d/cap-mlcc-2-2uf-x7r-25v-0603/dp/4335731) | |
| S6C3 | 4.7uF capacitor | 0805 >= 50V 10% X7R | [GRM21BZ71H475KE15K](https://uk.farnell.com/murata/grm21bz71h475ke15k/cap-4-7uf-50v-mlcc-0805/dp/3582887) | |
| S6C4 | 10pF capacitor | 0402 >= 50V 5% C0G/NP0 | [GRM1555C1H100JA01D](https://uk.farnell.com/murata/grm1555c1h100ja01d/cap-mlcc-10pf-c0g-np0-50v-0402/dp/4326648) | |
| S6C5 | 22uF capacitor | 0805 >= 10V 20% X7R | [GMC21X7R226M10NT](https://www.digikey.co.uk/en/products/detail/cal-chip-electronics-inc/GMC21X7R226M10NT/22461324) | |
| S6C8 | 100nF capacitor | 0402 >= 50V 10% X7R | [GRM155R71H104KE14D](https://uk.farnell.com/murata/grm155r71h104ke14d/cap-0-1-f-50v-10-x7r-0402/dp/2611912) | |
| S6R1 | Oscillator frequency resistor | 0402 18.2K 1% | [RC0402FR-0718K2L](https://uk.farnell.com/yageo/rc0402fr-0718k2l/res-18k2-1-0-0625w-0402-thick/dp/3495542) | 18.2K == 2MHz |
| S6R2 | Output voltage divider resistor | 0402 226K 1% ANTI-SULFUR AEC-Q200 | [MCMR04X2263FTL](https://uk.farnell.com/multicomp-pro/mcmr04x2263ftl/res-226k-1-0-0625w-0402-ceramic/dp/2072796) | VOUT == 0.782V x (1 + S6R3/S6R2) == 4.24V, sets output voltage, keep 1%, anti-sulfur AEC-Q200 recommended |
| S6R3 | Output voltage divider resistor | 0402 1M 1% ANTI-SULFUR AEC-Q200 | [AF0402FR-071ML](https://uk.farnell.com/yageo/af0402fr-071ml/res-1m-1-0-063w-thick-film-0402/dp/4148383) | Sets output voltage, keep 1%, anti-sulfur AEC-Q200 recommended |
| S6R4 | Buck enable jumper | 0402 0R | Any 0402 0R jumper | Ties EN to VIN. Replace with 1M if fitting the optional enable divider - see note below |
| S6R5 | Enable voltage divider resistor | DNP | - | **Optional** - see note below |
| S6R6 | Enable voltage divider resistor | DNP | - | **Optional** - see note below |
| S7U1 | Reverse-blocking load switch | Active high 3.3v load switch with reverse blocking | [SiP32431DR3-T1GE3](https://www.ebay.co.uk/itm/178539837620) | |
| S7R1 | 100K resistor | 0402 100K 5% | [MCPWR02FTEP1003A](https://uk.farnell.com/multicomp-pro/mcpwr02ftep1003a/res-100k-1-thick-film-0402/dp/4538624) | |
| S7R2 | 1M resistor | 0402 1M 5% | [ERJ2RKF1004X](https://uk.farnell.com/panasonic/erj2rkf1004x/res-1m-1-0-1w-0402-thick-film/dp/2302957) | |
| S7C1 | 2.2uF capacitor | 0603 >= 25V 10% X7R | [GRM188Z71E225KE43D](https://uk.farnell.com/murata/grm188z71e225ke43d/cap-mlcc-2-2uf-x7r-25v-0603/dp/4335731) | |
| S7C2 | 100nF capacitor | 0402 >= 50V 10% X7R | [GRM155R71H104KE14D](https://uk.farnell.com/murata/grm155r71h104ke14d/cap-0-1-f-50v-10-x7r-0402/dp/2611912) | |
| S8U1 | ASM330LHHXTR accelerometer | ASM330LHHXTR | [ASM330LHHXTR](https://estore.st.com/en/products/mems-and-sensors/inemo-inertial-modules/asm330lhhx.html) | |
| S8C1 | 100nF capacitor | 0402 >= 50V 10% X7R | [GRM155R71H104KE14D](https://uk.farnell.com/murata/grm155r71h104ke14d/cap-0-1-f-50v-10-x7r-0402/dp/2611912) | |
| S8C2 | 10uF capacitor | 0603 >= 10V 20% X7R | [C1608X7R1A106M080AT](https://www.digikey.co.uk/en/products/detail/tdk/C1608X7R1A106M080AT/25595431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) | |
| S8C3 | 100nF capacitor | 0402 >= 50V 10% X7R | [GRM155R71H104KE14D](https://uk.farnell.com/murata/grm155r71h104ke14d/cap-0-1-f-50v-10-x7r-0402/dp/2611912) | |
| S8C4 | 100pF SDA filter capacitor | 0402 >= 50V 5% C0G / NP0 | [0402N101J500CT](https://uk.farnell.com/multicomp-pro/0402n101j500ct/cap-100pf-50v-5-c0g-np0-0402/dp/2496792) | |
| S8C5 | 100pF SCL filter capacitor | 0402 >= 50V 5% C0G / NP0 | [0402N101J500CT](https://uk.farnell.com/multicomp-pro/0402n101j500ct/cap-100pf-50v-5-c0g-np0-0402/dp/2496792) | |
| S8R1 | Accelerometer ferrite bead | Ferrite 600R 300mA | [BLM15AG601SH1D](https://uk.farnell.com/murata/blm15ag601sh1d/ferrite-bead-0-6ohm-0-3a-0402/dp/2470354) | |
| S11U1 | Ideal diode | LM66100 | [LM66100](https://www.ebay.co.uk/itm/178539979903) | |
| S11U2 | Shunt voltage reference | ATL431BQDBZR SOT-23 | [ATL431BQDBZR](https://www.ebay.co.uk/itm/178539382502) | 2.5V, 0.5%, low Iq |
| S11Q1 | OVP series MOSFET | SQ2361 SOT-23 | [SQ2361CES-T1_BE3](https://www.ebay.co.uk/itm/178539853850) | |
| S11Q2 | OVP gate drive PNP | BC856BLT1G SOT-23 | [BC856BLT1G](https://www.ebay.co.uk/itm/178539823265) | |
| S11D1 | 15V Zener diode (Vgs clamp) | BZX84C15 | [BZX84C15](https://uk.farnell.com/multicomp-pro/bzx84c15/zener-diode-0-3w-15v-sot-23/dp/2675186) | |
| S11R1 | PNP base pull-up | 0402 10K 1% | [CRCW040210K0FKED](https://uk.farnell.com/vishay/crcw040210k0fked/res-10k-1-0-063w-0402-thick-film/dp/1469669) | |
| S11R2 | MOSFET gate pulldown | 0402 1M 1% | [ERJ2RKF1004X](https://uk.farnell.com/panasonic/erj2rkf1004x/res-1m-1-0-1w-0402-thick-film/dp/2302957) | |
| S11R3 | Hysteresis resistor | 0603 33M 5% | [MCHVR03JTHX3305](https://uk.farnell.com/multicomp-pro/mchvr03jthx3305/res-33m-5-0-1w-0603-thick-film/dp/2825824) | |
| S11R4 | ATL431 cathode / PNP base resistor | 0805 15K 1% ANTI-SULFUR AEC-Q200 | [MCMR08X1502FTL](https://uk.farnell.com/multicomp-pro/mcmr08x1502ftl/res-15k-1-0-125w-0805-ceramic/dp/2073646) | anti-sulfur AEC-Q200 recommended, must be 0805 for current handling in fault conditions |
| S11R5 | OVP divider (top) | 0402 1M 1% ANTI-SULFUR AEC-Q200 | [AF0402FR-071ML](https://uk.farnell.com/yageo/af0402fr-071ml/res-1m-1-0-063w-thick-film-0402/dp/4148383) | Sets trip point, keep 1%, anti-sulfur AEC-Q200 recommended |
| S11R6 | OVP divider (bottom) | 0402 1.05M 1% | [RC0402FR-071M05L](https://uk.farnell.com/yageo/rc0402fr-071m05l/res-1m05-1-0-063w-thick-film-0402/dp/3951647) | Sets trip point, keep 1% |
| S11C1 | 47uF capacitor | 1210 >= 10V 20% X7R | [CL32B476MPJNNNE](https://uk.farnell.com/semco/cl32b476mpjnnne/cap-mlcc-47uf-10vdc-x7r-1210/dp/5109745) | Was S6C6 in v3.1 |
| S11C2 | 47uF capacitor | 1210 >= 10V 20% X7R | [CL32B476MPJNNNE](https://uk.farnell.com/semco/cl32b476mpjnnne/cap-mlcc-47uf-10vdc-x7r-1210/dp/5109745) | Was S6C7 in v3.1 |
| S11C3 | 3.3pF reference filter capacitor | 0402 >= 50V ±0.25pF C0G / NP0 | [CGA2B2C0G1H3R3C050BA](https://uk.farnell.com/tdk/cga2b2c0g1h3r3c050ba/cap-3-3pf-50v-c0g-np0-0402/dp/2210780) | |
| S13R1 | LED resistor | 0402 1K 5% | [CRCW04021K00FKED](https://uk.farnell.com/vishay/crcw04021k00fked/res-1k-1-0-063w-0402-thick-film/dp/1469662) | |
| S13R2 | LED resistor | 0402 1K 5% | [CRCW04021K00FKED](https://uk.farnell.com/vishay/crcw04021k00fked/res-1k-1-0-063w-0402-thick-film/dp/1469662) | |
| S13R3 | LED resistor | 0402 1K 5% | [CRCW04021K00FKED](https://uk.farnell.com/vishay/crcw04021k00fked/res-1k-1-0-063w-0402-thick-film/dp/1469662) | |
| S13D1 | Status LED | 0603 | [150060RS86000](https://uk.farnell.com/wurth-elektronik/150060rs86000/led-red-800mcd-624nm/dp/3408608) | |
| S13D2 | Status LED | 0603 | [150060RS86000](https://uk.farnell.com/wurth-elektronik/150060rs86000/led-red-800mcd-624nm/dp/3408608) | |
| S13D3 | Status LED | 0603 | [150060RS86000](https://uk.farnell.com/wurth-elektronik/150060rs86000/led-red-800mcd-624nm/dp/3408608) | |
| S15J1 | u.FL PCB connector | 50 ohm | [U.FL-R-SMT(01)](https://www.ebay.co.uk/itm/178540053901) | |
| S15J2 | SMA PCB connector | 50 ohm | [SMA-J-P-H-RA-TH1](https://www.ebay.co.uk/itm/178540028662) | |
| S15J3 | u.FL PCB connector | 50 ohm | [U.FL-R-SMT(01)](https://www.ebay.co.uk/itm/178540053901) | |
| S15J4 | SMA PCB connector | 50 ohm | [SMA-J-P-H-RA-TH1](https://www.ebay.co.uk/itm/178540028662) | |
| S15FB1 | Ferrite bead | 600 ohm | [BLM15PX601SZ1D](https://uk.farnell.com/murata/blm15px601sz1d/ferrite-bead-0-9a-0-23ohm-0402/dp/3678458) | |
| S15L1 | RF inductor | 0603 47-68 nH, SRF > 2GHz | [LQW18AN68NJ00D](https://www.ebay.co.uk/itm/178539565608) | |
| S15C1 | 47pF RF capacitor | 0402 >= 50V 5% C0G / NP0 | [0402N470J500CT](https://uk.farnell.com/multicomp-pro/0402n470j500ct/cap-47pf-50v-5-c0g-np0-0402/dp/2496804) | |
| S15C2 | 100pF RF capacitor | 0402 >= 50V 5% C0G / NP0 | [0402N101J500CT](https://uk.farnell.com/multicomp-pro/0402n101j500ct/cap-100pf-50v-5-c0g-np0-0402/dp/2496792) | |
| S15C3 | 10nF RF capacitor | 0402 >= 50V 5% C0G / NP0 | [GRM1555C1H103JE01D](https://uk.farnell.com/murata/grm1555c1h103je01d/cap-mlcc-0-01uf-5-c0g-50vdc-0402/dp/4803046RL) | |
| S15C4 | 2.2uF capacitor | 0603 >= 25V 10% X7R | [GRM188Z71E225KE43D](https://uk.farnell.com/murata/grm188z71e225ke43d/cap-mlcc-2-2uf-x7r-25v-0603/dp/4335731) | |
| S15D1 | DNP - ESD protection diode (GSM path) | DNP - not necessary | | |
| S15D2 | DNP - ESD protection diode (GPS path) | DNP - not necessary | | |
| S15R1 | Bias tee feed resistor | 0508 15R 5% 1W | [3430A2F15RTDF](https://uk.farnell.com/cgs-te-connectivity/3430a2f15rtdf/res-15r-1w-thick-film-0508-wide/dp/4206818) | |
| - | u.FL cable - LTE | 50 ohm 35mm | [U.FL-2LPHF6-04N1TV-A-35](https://uk.farnell.com/hirose-hrs/u-fl-2lphf6-04n1tv-a-35/cbl-assy-u-fl-r-a-plug-r-a-plug/dp/4294251) | |
| - | u.FL cable - GPS | 50 ohm 35mm | [U.FL-2LPHF6-04N1TV-A-35](https://uk.farnell.com/hirose-hrs/u-fl-2lphf6-04n1tv-a-35/cbl-assy-u-fl-r-a-plug-r-a-plug/dp/4294251) | |
| - | JST power cable | Ultra-thin MX1.25 51146 | [10PCS MX1.25 51146 Cable](https://www.ebay.co.uk/itm/178550497683) | |

### Optional: buck enable divider (S6R4/S6R5/S6R6)

S6R4/S6R5/S6R6 form a 3-resistor divider on the LT8609 EN/UV pin that gives
the buck a defined under-voltage lockout with hysteresis: it won't start until
the supply reaches ~5.6V and will shut off if the supply falls to ~4.3V, then
needs ~5.6V again to restart. This is aimed at ISO 16750-2 low-voltage and
drop-out tests. The divider draws around ~9 µA continuously from the 12V
input, on top of the ~35.5 µA the rest of the board draws asleep, so it is
DNP by default.

**Default build (no divider):** fit S6R4 as a `0402 0R` jumper and leave S6R5
and S6R6 unpopulated. EN is tied directly to VIN and the buck runs whenever
the input is present, relying on the LT8609's own internal UVLO.

**With the divider:** fit the three parts below in place of the jumper.

| Item | Description | Specification | Example | Notes |
|---|---|---|---|---|
| S6R4 | Enable voltage divider resistor | 0402 1M 1% ANTI-SULFUR AEC-Q200 | [AF0402FR-071ML](https://uk.farnell.com/yageo/af0402fr-071ml/res-1m-1-0-063w-thick-film-0402/dp/4148383) | Replaces the 0R jumper. Sets enable/disable voltage, keep 1%, anti-sulfur AEC-Q200 recommended |
| S6R5 | Enable voltage divider resistor | 0402 243K 1% ANTI-SULFUR AEC-Q200 | [MCMR04X2433FTL](https://uk.farnell.com/multicomp-pro/mcmr04x2433ftl/res-243k-1-0-0625w-0402-ceramic/dp/2072824) | Sets enable/disable voltage, keep 1%, anti-sulfur AEC-Q200 recommended |
| S6R6 | Enable voltage divider resistor | 0402 3.92M 1% | [CRCW04023M92FKED](https://uk.farnell.com/vishay/crcw04023m92fked/res-3m92-1-0-063w-0402-thick-film/dp/2141113) | |

With EN threshold 1.05V rising / 1.00V falling and VOUT = 4.24V:
K = 1 + S6R4/S6R5 + S6R4/S6R6, VIN\_on = K x 1.05 ≈ 5.6V,
VIN\_off = K x 1.00 - S6R4 x VOUT / S6R6 ≈ 4.3V.
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

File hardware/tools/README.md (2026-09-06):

# Hardware tools

## board_features.py

Generates an annotated "features" image from a photo of an assembled board
and the KiCad PCB file: each listed feature gets a leader line from its
location on the photo to a label in the margin.

```
cd hardware/l0destar_v3.2
python3 ../tools/board_features.py features.yaml --check
```

That writes `images/features.png` and `images/features_check.png`. The check
image overlays every footprint outline and reference on the photo so you can
confirm the registration before trusting the callouts. Delete it afterwards or
leave it out of commits.

Dependencies: numpy, scipy, Pillow, PyYAML (all in the usual venv). It parses
the `.kicad_pcb` directly, so it does not need KiCad's Python bindings.

### How it locates the board

1. The PCB is separated from the background by colour (the background is
   estimated from the image border, so it should be plain and reasonably
   uniform). Overhanging connectors and wires are ignored because each edge is
   fitted with RANSAC.
2. Orientation is picked by projecting the mounting holes through each of the
   four candidate rotations and checking which one lands them on
   see-through spots. Override with `--rotate 0|90|180|270` if it guesses
   wrong; the per-rotation scores are printed.
3. A homography from board mm to photo px is solved from the corners, then
   refined with the detected hole centres (residual is printed, a few px is
   normal).

If detection fails, pass the corners by hand:
`--corners "x,y x,y x,y x,y"` (top-left, top-right, bottom-right, bottom-left,
photo pixels).

### Config file

```yaml
pcb: l0destar.kicad_pcb
photo: images/pcb0.png
output: images/features.png
title: l0destar v3.2          # optional
subtitle: ...                  # optional
auto_sides: [left, right, top, bottom]   # sides used when a feature has no `side`
crop_pad_mm: 3                 # margin around the board outline
crop_max_mm: {left: 5, right: 14, top: 3, bottom: 3}   # how far to follow overhangs
style:
  board_width: 2000            # px, output scale
  font_size: 26
  accent: "#ff6a00"
features:
  - refs: [S1J1]               # one or more designators, grouped into one callout
    label: "Main connector\n6-pin Molex Micro-Fit 3.0"   # first line bold
    side: left                 # left / right / top / bottom (optional)
    offset: [-16, 0]           # nudge the anchor, mm (optional)
  - at: [57.1, 90.2]           # or place the anchor by PCB coordinate
    label: "Somewhere"
```

`--init --pcb x.kicad_pcb --photo p.png` prints a starter config listing the
connectors, ICs, LEDs, test points and holes found in the PCB.
`--list --pcb x.kicad_pcb` dumps every footprint with position and rotation.

Labels on the top and bottom are staggered into rows when they do not fit in
one; if the leaders get too tangled, move some features to `left` or `right`
or shorten the text.

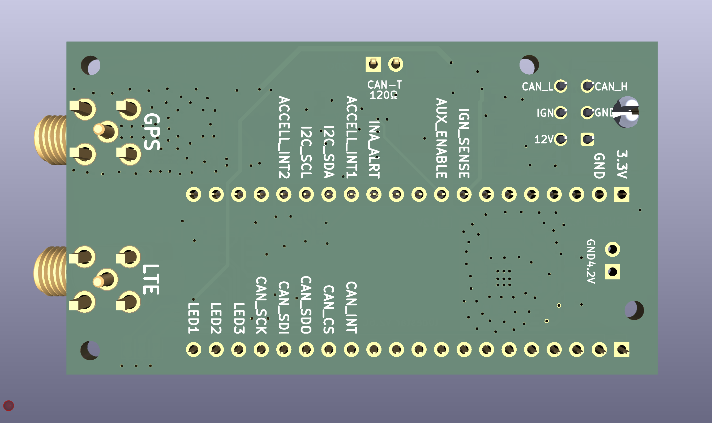
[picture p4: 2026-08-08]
hardware/l0destar_v2.6_can/images/pcb4.png

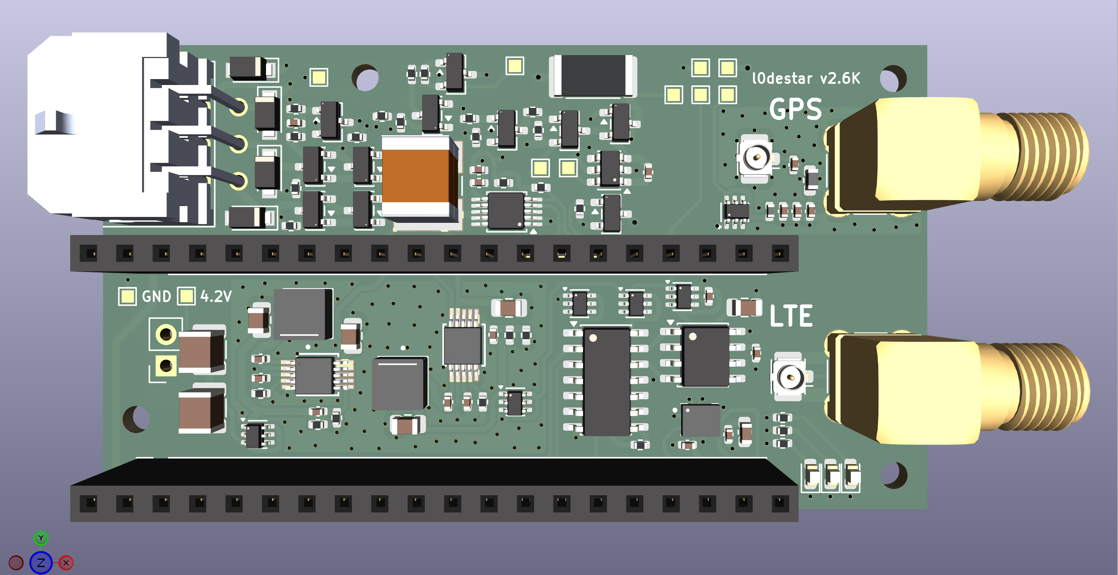
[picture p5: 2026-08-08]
hardware/l0destar_v2.6_kline/images/pcb2.png

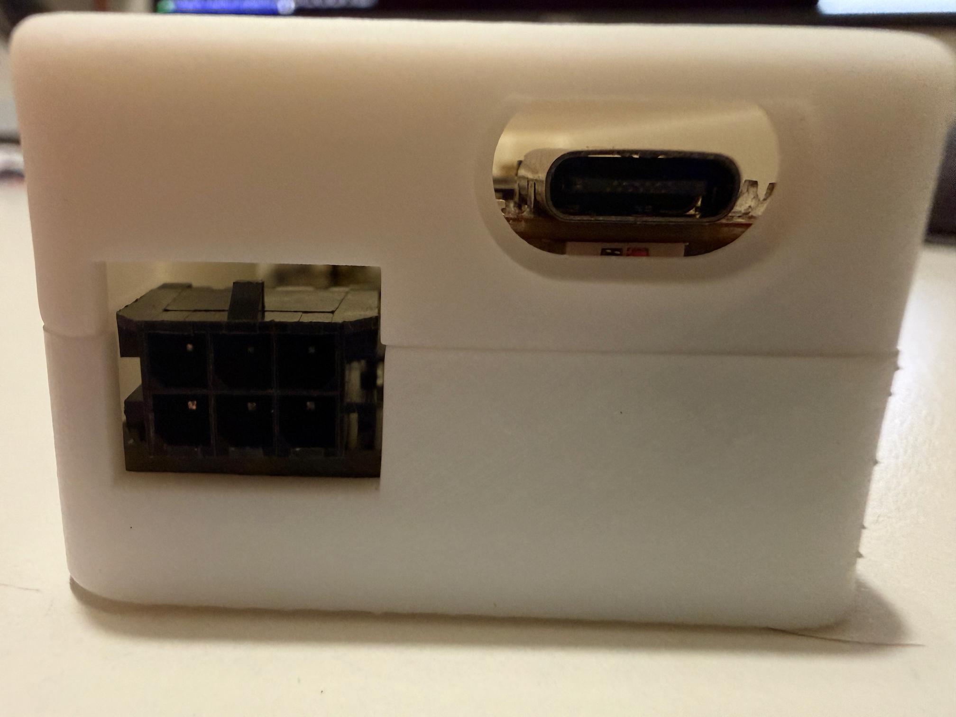
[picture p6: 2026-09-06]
hardware/enclosure/v3.4/images/enclosure4.png

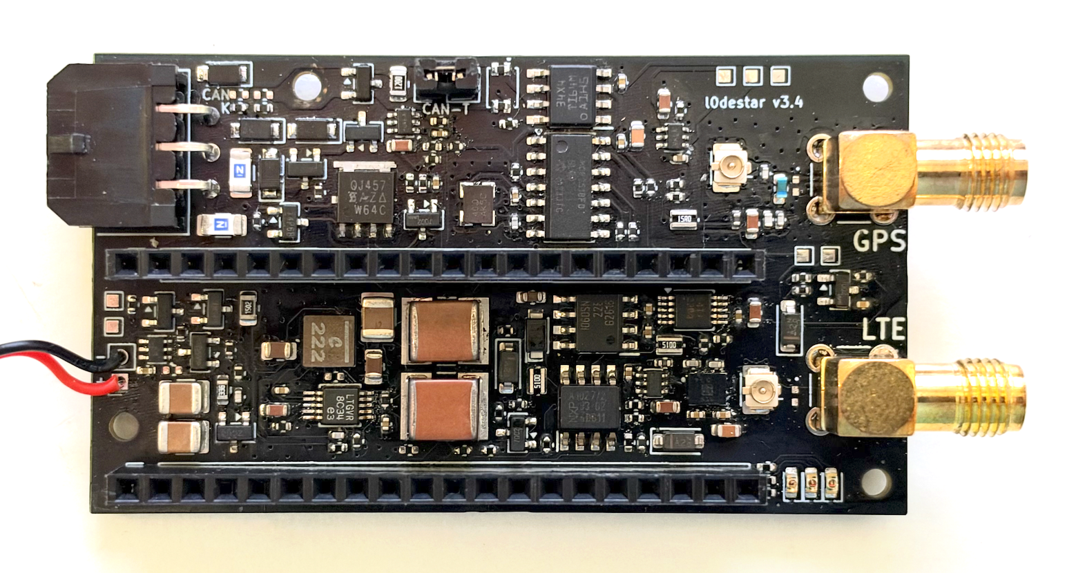
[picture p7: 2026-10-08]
hardware/l0destar_v3.4/images/pcb0.png

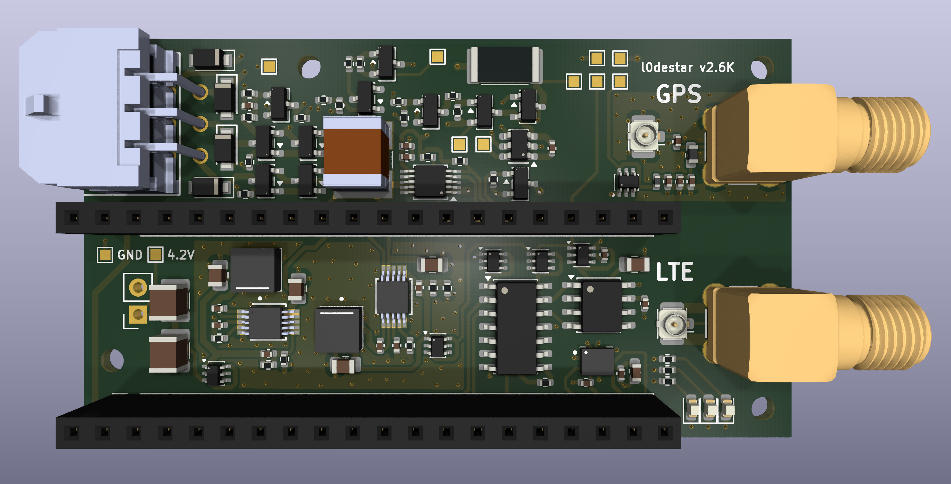
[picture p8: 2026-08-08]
hardware/l0destar_v2.6_kline/images/pcb3.png

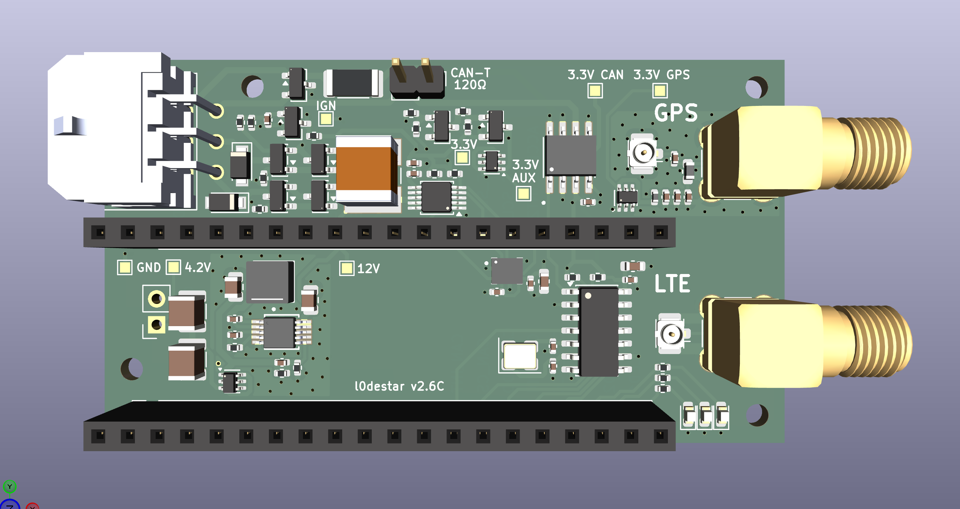
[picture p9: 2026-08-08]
hardware/l0destar_v2.6_can/images/pcb2.png

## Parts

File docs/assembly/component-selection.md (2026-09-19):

# Component selection

The bill of materials is in the
[v3.4 README](https://github.com/m4rkw/l0destar/blob/master/hardware/l0destar_v3.4/README.md).
This page helps you decide what to build, explains how the bill of materials is organised, and
calls out the parts that must not be casually substituted.

!!! warning "The bill of materials is an example, not a verified BOM"
    Working boards have been built with many of the listed parts, but not necessarily from the
    same vendor, series or batch. Check every part against its current datasheet - footprint,
    tolerance, voltage rating - before you buy. The specifications in the bill of materials are
    minimums; some example links point at tighter-tolerance or higher-rated parts than the minimum
    because that is what the author buys.

## Choose the vehicle interface

Every v3.4 board has the same PCB. The vehicle diagnostic interface is optional and comes in two
flavours; you populate the parts for the one you want, bridge the matching configuration pads, and
tell the firmware which one is fitted.

| Build | Parts to fit | Pads to bridge | Firmware setting | What it gives you with firmware 0.4.x |
|---|---|---|---|---|
| No interface | Required parts only | none | `CONFIG_APP_OBD_MODE=0` | Position, speed, battery voltage, ignition state, accelerometer alerts |
| CAN-FD | Required + CAN bus parts | S5R1 and S5R3 | `CONFIG_APP_OBD_MODE=1` | The CAN-FD hardware, without vehicle data yet - see below |
| K-wire | Required + K-wire parts | S5R2 and S5R4 | `CONFIG_APP_OBD_MODE=2` | OBD-II engine data and stored fault codes |

To see what your vehicle uses, look at its OBD socket: CAN diagnostics use pins 6 (CAN high) and 14
(CAN low); the K wire is pin 7, with the optional L wire on pin 15.

- **K-wire.** The firmware opens a KWP2000 (ISO 14230) session over the K wire and can report
  engine RPM, vehicle speed, coolant and intake temperature, load, throttle, mass air flow, timing
  advance, fuel trims, fuel system status and the check-engine lamp with every record, and send
  the stored fault codes after the ignition comes on and whenever they change during a drive. The same wire carries ISO 9141-2 and
  manufacturer-specific pre-OBD protocols such as VAG KW1281, which the firmware does not speak.
  Each vehicle needs a one-off discovery run first.
- **CAN-FD.** The CAN block - an MCP2518FD CAN-FD controller and a CAN-FD transceiver - handles
  both classic CAN and CAN-FD. On a v3.1 board, with the MAX33041E transceiver that earlier boards
  fit, it passed about 60,000 frames in both modes from 125kbps up to an 8Mbps FD data phase (see
  the [CAN bench test report](https://github.com/m4rkw/l0destar/blob/master/firmware/CAN_BENCH_REPORT.md)).
  8Mbps is beyond the MAX33041E's 5Mbps rating, and there it logged 2 data-phase bit errors, both
  retried and delivered; the TCAN3414DR that v3.4 specifies has not been tested.
  The firmware powers it, puts it to sleep and has bench tests for it, but **firmware 0.4.x does
  not read any vehicle data over CAN**, and the interface has not been tried in a vehicle. Build it
  if you intend to work on CAN support.
- **No interface.** The smallest and cheapest build, and the right one if you only want a
  tracker.

Both sets of interface parts can be populated, but only one interface may be enabled at a time.

!!! danger "Never bridge the CAN and K pads together"
    The pads route the same two connector pins to one interface or the other. Connecting both at
    once gives unpredictable behaviour. The full pad table is in the
    [hardware reference](../reference/hardware.md#interface-selection-pads).

## How the bill of materials is organised

The README splits the parts into sections:

| Section | Contents |
|---|---|
| Bill of materials - required | Everything every build needs, including the Connect Kit, cables and connectors |
| Optional: buck enable divider | Three resistors that give the buck converter a defined under-voltage cut-off; not fitted by default |
| Bill of materials - CAN bus parts | Only for a CAN build |
| Optional: CAN common-mode choke | Part of the CAN build, but optional |
| Bill of materials - K-wire parts | Only for a K-wire build |
| Parts list | The same parts aggregated with quantities per board: `All` rows plus the `CAN` or `K-wire` rows for your build, and the `Optional` rows if you fit the buck enable divider |

Designators start with the schematic sheet they belong to, which helps when finding parts on the
board:

| Prefix | Subsystem |
|---|---|
| S1 | Main connector, Connect Kit headers and power header, I2C pull-ups |
| S2 | 12V power input protection |
| S3 | INA228 battery voltage monitor |
| S4 | Ignition sensing |
| S5 | Interface configuration pads |
| S6 | Buck converter |
| S7 | Switched auxiliary power rails |
| S8 | Accelerometer |
| S9 | CAN interface |
| S10 | K-wire interface |
| S11 | Over-voltage protection for the Connect Kit |
| S12 | Test points |
| S13 | Status LEDs |
| S15 | Antenna connectors, bias tee and ESD protection |

## Optional parts

**Buck enable divider (S6R4, S6R5, S6R6).** By default S6R4 is a 0402 0R jumper and S6R5 and S6R6
are not fitted, so the buck runs whenever input voltage is present and relies on the LT8609A's own
internal under-voltage lockout. Fitting the divider instead (S6R4 1M, S6R5 243K, S6R6 3.92M, all
1%) makes the buck start only above about 5.6V and shut off below about 4.3V by calculation (a v3.3 board measured 5.14V on and 4.47V off), which gives clean
behaviour in ISO 16750-2 style low-voltage and drop-out events. It costs around 9µA of sleep
current at 12V, which is why it is not fitted by default. Values and formula are in the
[hardware reference](../reference/hardware.md#buck-enable-divider).

**CAN common-mode choke (S9FL1).** An ACT1210-101-2P-TL00 in series with CAN high and CAN low,
which improves emissions and common-mode noise rejection. CAN works without it.

!!! warning "If you leave out the CAN choke, bridge its pads"
    Without S9FL1 the CAN high and CAN low lines are open circuit. Fit two 0402 0R resistors
    across its footprint to join each line through - an 0402 fits the ACT1210 pads.

**CAN termination (S9R3 and S9J1).** A 120R resistor in series with a 2-pin header. Fit a shunt on
the header only if the tracker is at the end of the CAN bus; plugged into a vehicle's OBD socket it
normally is not.

## Parts that need care

The reasoning behind most of these is in
[PROTECTION.md](https://github.com/m4rkw/l0destar/blob/master/hardware/l0destar_v3.4/PROTECTION.md).
It is desk analysis rather than a test report, but it records why each choice was made and which
"improvements" have already been considered and rejected.

### 12V input

| Part | Designators | Why it matters |
|---|---|---|
| All capacitors on the 12V rails | - | Must be rated 50V or more to survive transients. |
| 47µF 50V 2220, TDK CKG57NX7R1H476M500JH | S2C1, S2C2 | Bulk capacitance that soaks up ISO 7637-2 pulse 2a (+112V behind 2 ohms for 50µs). These are leadframe-stacked parts: the metal frame, not the ceramic, is soldered to the board, which is the flex-crack protection. An AEC-Q200 version exists as CKG57NX7R1H476M500JJ. |
| 10µF 50V 1210 soft termination, Taiyo Yuden MCJCU32MLB7106KPPDT1 | S2C3 | Keeps the pulse 2a peak in bounds even if both 47µF parts arrive at the bottom of their tolerance. It is a plain chip, so it must be a soft-termination part. |
| 2A 1206 time-lag fuse, Littelfuse 0407002.WRA | S2F1, S2F2 | One per 12V input, a fire backstop for installations without harness fuses. Must stay time-lag: a fast-acting 2A fuse is at risk from pulse 2a and hot-plug inrush. |
| 33V TVS, Nexperia PTVS33VS1UTR,115 | S2D2, S2D4 | Breaks down at 36.7V minimum, so a 35V suppressed load dump passes straight through to the 42V-rated buck instead of being clamped. **Do not fit a lower-voltage TVS**: it would try to absorb the whole 400ms load dump, far beyond its rating, and fail short. |
| Reverse-polarity P-FET, Vishay SQJ457EP-T1_BE3 | S2Q2 | On the permanent input, where it carries the pulse 2a charging current (about 45A peak against a 100A pulsed rating). Do not replace it with the smaller SQ2361. |
| Reverse-polarity P-FET, SQ2361 | S2Q1 | On the ignition input, which only feeds a sense divider. |
| 15V zener, BZX84C15 | S2D1, S2D3 | Gate protection for the two input FETs. |

Every bulk capacitor on the permanent 12V rail must be either a leadframe-stacked part or a
soft-termination chip. A plain ceramic chip that cracks from board flex usually fails short, and on
a rail fed straight from the battery that means a continuous fault current.

### Regulation and protection

| Part | Designators | Why it matters |
|---|---|---|
| LT8609AIMSE buck converter | S6U1 | 42V absolute maximum input and very low quiescent current, so it adds almost nothing to the sleep budget. |
| Coilcraft XFL4020-222ME inductor | S6L1 | 2.2µH buck inductor. |
| Output divider, S6R2 226K and S6R3 1M | S6R2, S6R3 | Sets the output to 0.782V x (1 + S6R3/S6R2) = 4.24V. Keep them 1%; anti-sulfur AEC-Q200 parts recommended. |
| Frequency resistor, 18.2K 1% | S6R1 | Sets the switching frequency to 2MHz. |
| Over-voltage protection stage | S11U2 (ATL431BQDBZR), S11Q1, S11Q2, S11D1, S11R1-S11R6, S11C1-S11C3 | Disconnects the Connect Kit's supply if the 4.2V rail rises above about 4.95V, releasing below about 4.80V. The Connect Kit's battery input and the nRF9151 both have a 5.5V absolute maximum, so this is what saves the module from a buck fault. Keep the S11R5/S11R6 divider at 1% - a 5% pair widens the trip window at both ends. S11R4 must be 0805 for current handling in fault conditions. |
| LM66100 ideal diode | S11U1 | Between the protection stage and the Connect Kit. Its CE pin tied to its output is a documented configuration, not a wiring error. |

### Sensing

| Part | Designators | Why it matters |
|---|---|---|
| ST ASM330LHHXTR accelerometer | S8U1 | Pads 10 and 11 must be unconnected, as they are on v3.4. Fed through ferrite bead S8R1, with 100pF filter capacitors S8C4 and S8C5 on the I2C lines. |
| INA228 voltage monitor | S3U1 | Measures the vehicle battery voltage over I2C. |
| I2C pull-ups, 1.8K 1% | S1R1, S1R2 | Sized to keep the bus rise time in spec. |
| 2N7002 | S4Q1, and S7Q1 and S10Q1 on K-wire builds | Any manufacturer's 2N7002 is acceptable: the gate dividers keep every vendor's gate rating in spec. |
| SiP32431DR3-T1GE3 load switch | S7U1 (GPS), S7U2 (CAN), S7U4 (K-wire) | Reverse-blocking 3.3V switches that power each auxiliary rail only when the firmware needs it. |

### Interfaces and RF

| Part | Designators | Why it matters |
|---|---|---|
| TCAN3414DR CAN transceiver | S9U1 | Fully rated for CAN-FD, with timing specified at 2, 5 and 8Mbps. The MAX33041EASA+ fitted on v3.3 has the same footprint and pinout and can be fitted instead; it is rated to 5Mbps. |
| MCP2518FD controller with a 40MHz crystal | S9U2, S9Y1 (ECS-400-18-33-JGN-TR3), S9C2, S9C3 | CAN-FD controller on SPI. |
| NUP2105L | S9D1 | CAN bus protection. |
| NXP TJA1027T/20 transceiver | S10U1 | It has no transmit dominant time-out, which is what lets it hold the K wire low for the 200ms bits of a 5-baud init. A LIN transceiver with a time-out cannot do that. |
| Diodes Inc. AL5809-90P1-7 | S10U2 | Caps the L-line pull-down at 90mA and shuts down thermally, so an L wire shorted to battery cannot destroy the pull-down transistor or the nRF9151. |
| ITS4060SSJNXUMA1 12V load switch | S7U3 | Switches the K-wire 12V rail. Its 40V absolute maximum is the lowest rating on the 12V rail. |
| 510R 1W 0508 resistors | S10R3, S10R4 | K and L line pull-ups. |
| 33V TVS, PTVS33VS1UTR,115 | S10D2, S10D4 | Protection on the K and L lines. |
| 15R 1W 0508 resistor | S15R1 | The bias-tee feed that powers an active GNSS antenna from the switched 3.3V GPS rail. |
| RF inductor, 47-68nH with SRF above 2GHz | S15L1 | Part of the bias tee; the example is a Murata LQW18AN68NJ00D. |
| TPD1E05U06DPYR ESD diodes | S15D1, S15D2 | ESD protection at the LTE and GPS antenna connectors. |
| SMA-J-P-H-RA-TH1 and U.FL-R-SMT(01) | S15J1-S15J4 | Antenna connectors. |
| Molex 43045-0600 | S1J1 | 6-pin Micro-Fit 3.0 vehicle connector. |

## Buying the parts

- Buy spares of every 0402 part.
- Work from the **Parts list** table in the README, taking the `All` rows plus the rows for your
  interface, and the `Optional` rows if you fit the buck enable divider. Treat the specification
  column as the minimum, not the part number.
- Use a distributor you trust. The links in the README are for identification and go stale.

## Enclosure hardware

If you print the enclosure from
[`hardware/enclosure/v3.3/`](https://github.com/m4rkw/l0destar/tree/master/hardware/enclosure/v3.3),
you also need:

| Item | Example |
|---|---|
| M2 heat-set threaded inserts | https://link.amazon/B0fiGzjDl |
| M2 x 10mm screws | https://link.amazon/B04Nlsa3c |
| Heat-set insert tip for C210-style irons (optional, makes straight inserts much easier) | https://link.amazon/B01C41sjy |

The enclosure is a prototype that has not been tested for strength, vibration, heat, moisture,
UV or flammability, and the material you print it in affects all of those.

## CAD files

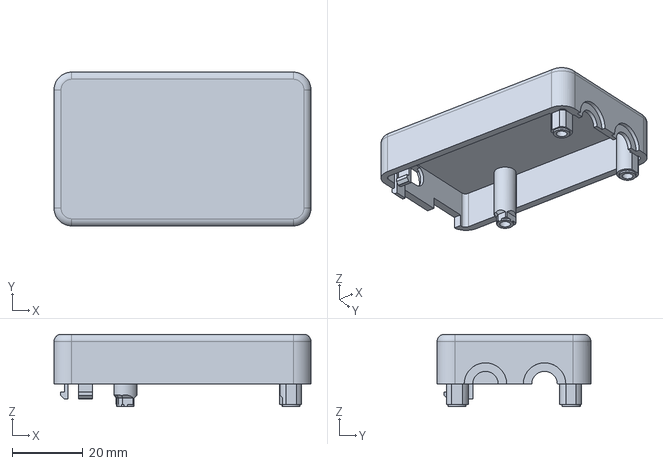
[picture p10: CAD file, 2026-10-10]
hardware/enclosure/v3.4/no_logo/enclosure_no_logo_top.step
72.5 x 43.4 x 20.4 mm

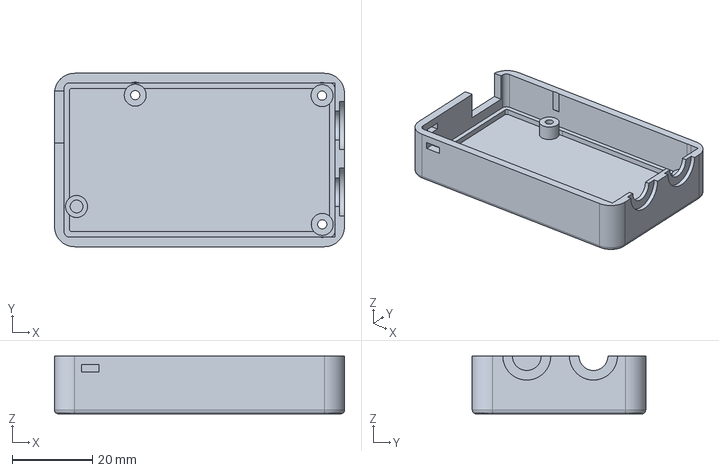
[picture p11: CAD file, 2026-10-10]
hardware/enclosure/v3.4/with_logo/enclosure_bottom.step
72.5 x 43.4 x 14.5 mm

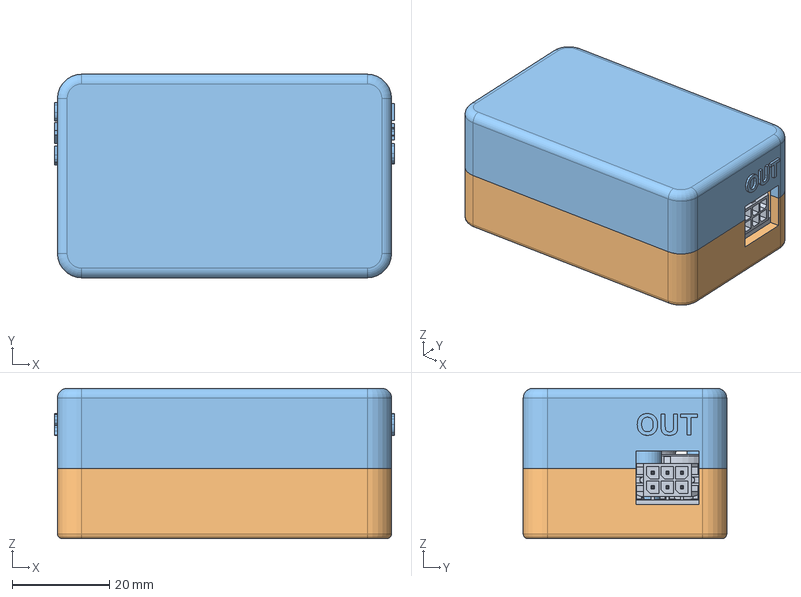
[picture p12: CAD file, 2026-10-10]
hardware/l0destar_battery_backup_v1.1/enclosure/enclosure.FCStd
70.1 x 42.0 x 31.0 mm
Mock_Board
Enclosure_Bottom
Enclosure_Top

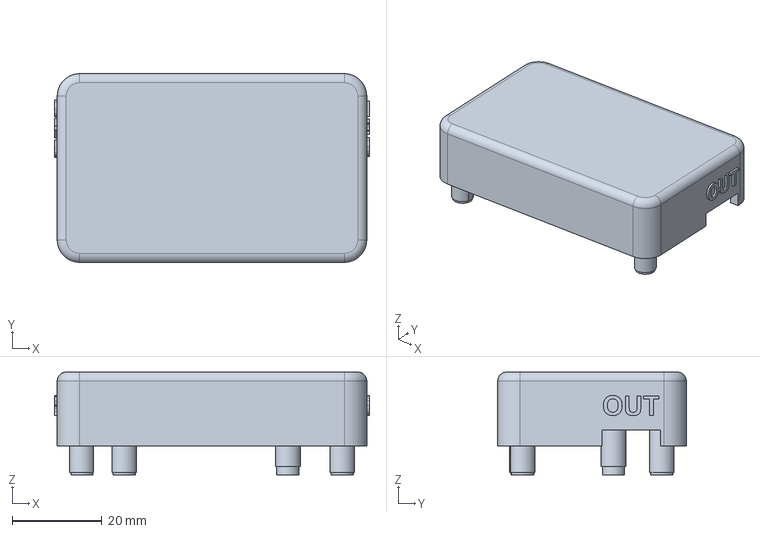
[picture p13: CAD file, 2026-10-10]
hardware/l0destar_battery_backup_v1.1/enclosure/enclosure_top.step
70.1 x 42.0 x 22.9 mm

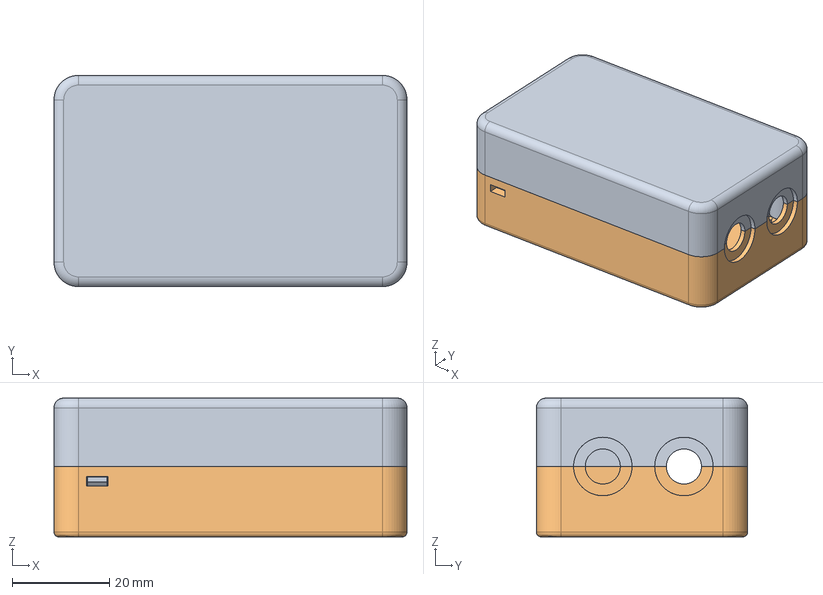
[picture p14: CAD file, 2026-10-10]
hardware/enclosure/v3.4/no_logo/enclosure_no_logo.FCStd
72.5 x 43.4 x 28.5 mm
Enclosure_Top
Enclosure_Bottom

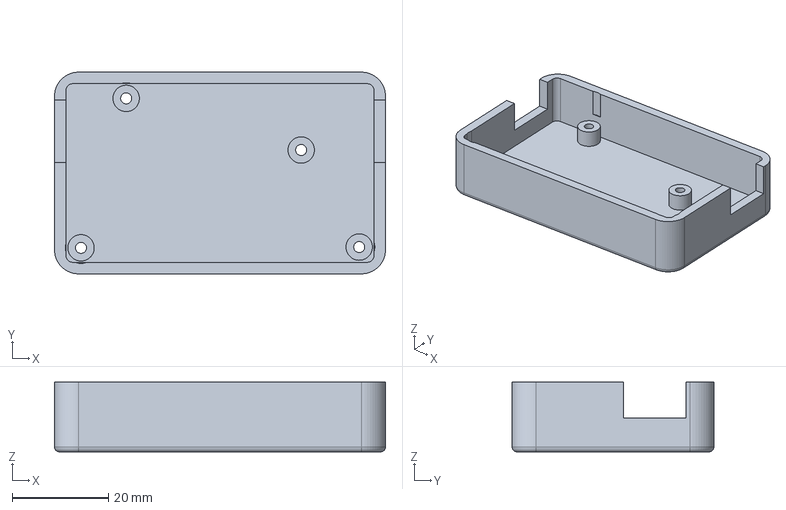
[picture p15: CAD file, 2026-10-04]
hardware/l0destar_battery_backup_v1.1/enclosure/enclosure_bottom.step
68.9 x 42.0 x 14.5 mm

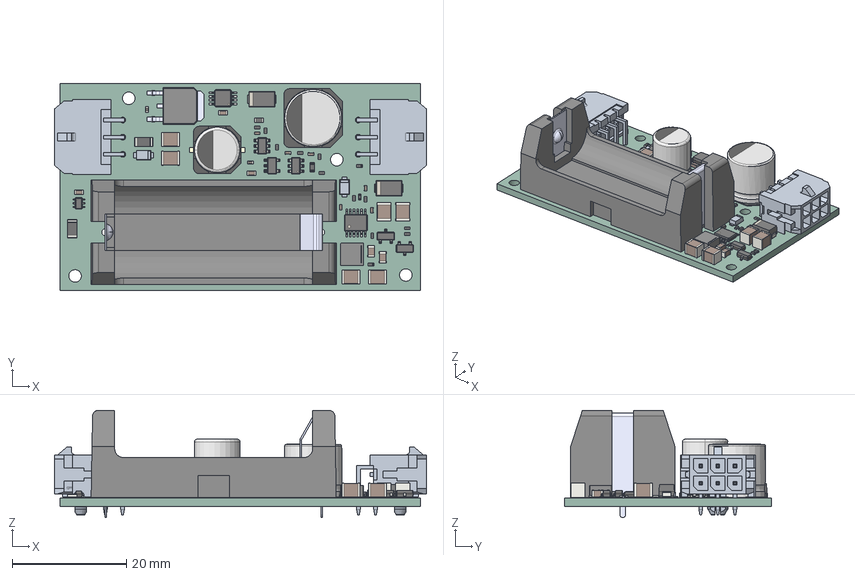
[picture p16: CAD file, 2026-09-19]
hardware/l0destar_battery_backup_v1.1/enclosure/board.step
65.1 x 36.2 x 18.8 mm
C_0402_1005Metric x 8
R_0402_1005Metric x 14
標準品ケースΦ10x9.3L SIDE CODE G
標準品座版Φ10 SIZE CODE G
標準品リード線Φ10 SIZE CODE G x 2
C_1210_3225Metric x 6
C_0805_2012Metric x 2
C_0603_1608Metric x 3
MSOP-12-1EP_3x4.039mm_P0.65mm_EP1.651x2.845mm
board 1.16.1 x 2
SOT-23-5
Fuse_1206_3216Metric x 2
SOT-23-6 x 2
VSSOP-8_3x3mm_P0.65mm
R_0603_1608Metric x 2
XFL4020-222ME
WSIZE CODE F-001
WSIZE CODE F-002
WSIZE CODE F-003 x 2
D_SMA x 2
SOT-23 x 2
SOT-363_SC-70-6
IRLR2905TRPBF
l0destar_PCB

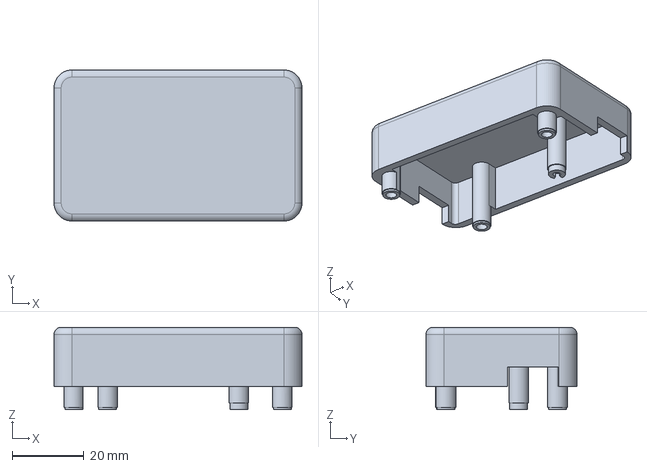
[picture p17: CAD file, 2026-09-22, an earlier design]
hardware/l0destar_battery_backup_v1.0/enclosure/enclosure_top.step
68.9 x 42.0 x 22.9 mm

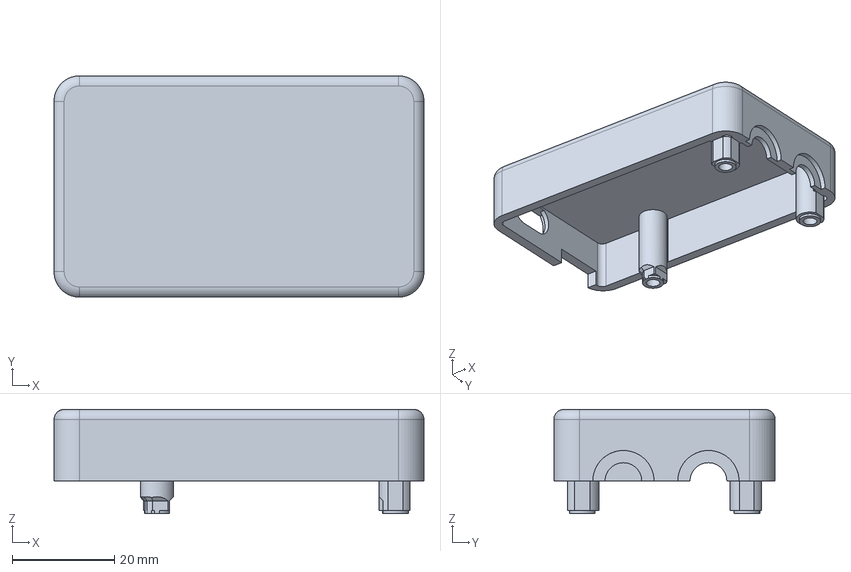
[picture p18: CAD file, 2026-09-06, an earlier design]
hardware/enclosure/v3.3/no_logo/enclosure_no_logo_top.step
72.5 x 43.4 x 20.4 mm

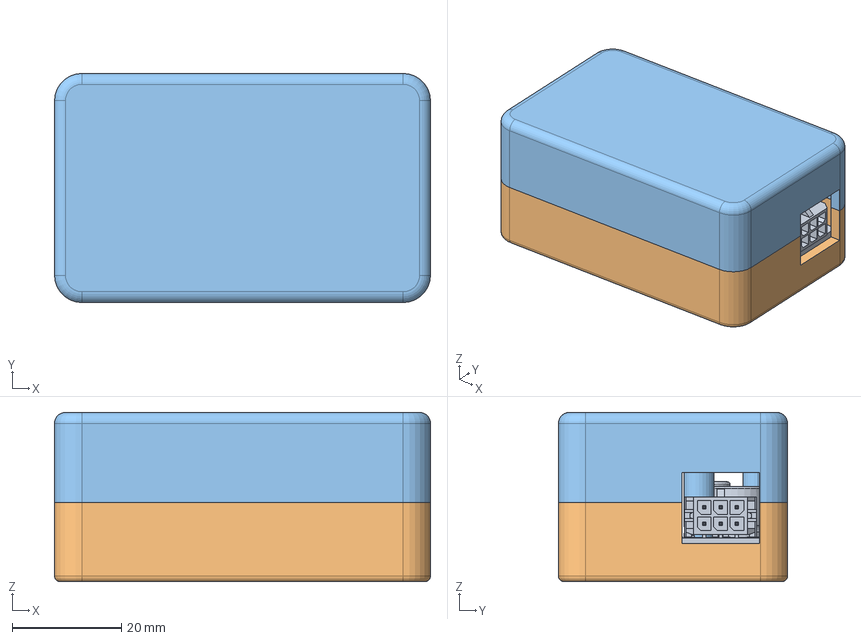
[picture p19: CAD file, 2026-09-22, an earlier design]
hardware/l0destar_battery_backup_v1.0/enclosure/enclosure.FCStd
68.9 x 42.0 x 31.0 mm
Mock_Board
Enclosure_Bottom
Enclosure_Top

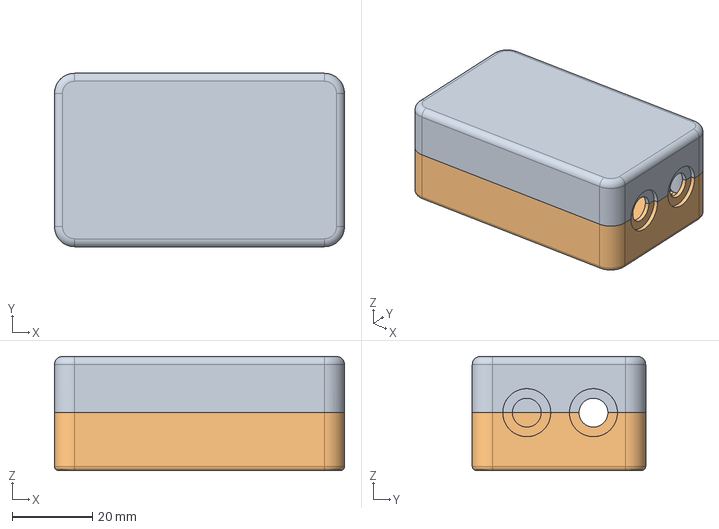
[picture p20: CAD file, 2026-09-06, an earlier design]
hardware/enclosure/v3.3/no_logo/enclosure_no_logo.FCStd
72.5 x 43.4 x 28.5 mm
Enclosure_Top
Enclosure_Bottom

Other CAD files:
hardware/enclosure/v3.4/no_logo/enclosure_no_logo_bottom.step
hardware/enclosure/v3.4/with_logo/enclosure_top.step
hardware/enclosure/v3.4/with_logo/enclosure.FCStd
hardware/enclosure/v3.3/no_logo/enclosure_no_logo_bottom.step
hardware/enclosure/v3.3/with_logo/enclosure_bottom.step
hardware/enclosure/v3.3/with_logo/enclosure_top.step
hardware/enclosure/v3.3/with_logo/enclosure.FCStd
hardware/enclosure/v3.3/no_logo/enclosure_no_logo_bottom.stl
hardware/enclosure/v3.3/no_logo/enclosure_no_logo_top.stl
hardware/enclosure/v3.3/with_logo/enclosure_bottom.stl
hardware/enclosure/v3.3/with_logo/enclosure_top.stl
hardware/enclosure/v3.4/no_logo/enclosure_no_logo_bottom.stl
hardware/enclosure/v3.4/no_logo/enclosure_no_logo_top.stl
hardware/enclosure/v3.4/with_logo/enclosure_bottom.stl
hardware/enclosure/v3.4/with_logo/enclosure_top.stl
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

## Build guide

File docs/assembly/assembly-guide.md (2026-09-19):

# Assembly guide

How to assemble a l0destar v3.4 board by hand. The board has not been built yet in this
revision, so treat this as a guide based on the v3.3 build and the v3.4 design files.

Before you start, have the [prerequisites](prerequisites.md) to hand, decide which
interface you are building ([component selection](component-selection.md)) and open
`hardware/l0destar_v3.4/l0destar.kicad_pcb` in KiCad so you can look up each part as you go.

!!! danger "Do not connect the Connect Kit yet"
    The Makerdiary Connect Kit is fitted last, and only after the board has passed the checks on
    the [board test](board-test.md) page. If any of the 12V rails
    are shorted to 3.3V or any of the GPIO pins it will likely be permanently
    damaged.

## Board layout

The descriptions below assume the Molex connector S1J1 is on the left edge and the SMA connectors
are on the right, as in this render of v3.4:

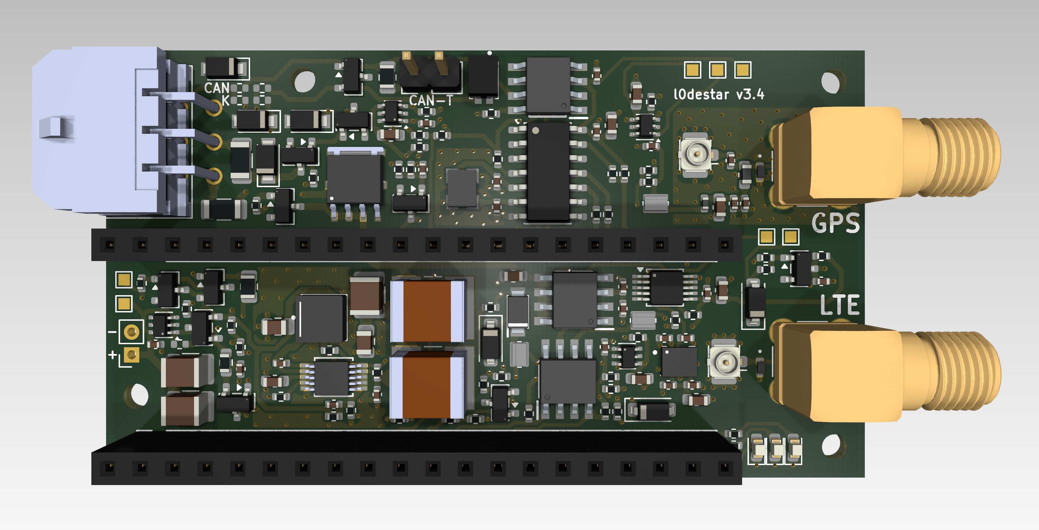
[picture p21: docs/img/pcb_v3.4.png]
l0destar v3.4 PCB render


- **Top left**, next to the Molex connector: the four configuration pads S5R1-S5R4, marked `CAN`
  and `K` on the silkscreen. They select which interface the connector's two bus pins are routed
  to.
- **Top middle**: the 2-pin CAN termination header S9J1, marked `CAN-T`.
- **Left edge**, between the two 20-pin headers: the OVP bypass pad S5R5, the holes for the
  Connect Kit power lead, S1J4 (marked `+` and `-`), and the test points S12TP1 (ground) and S12TP2 (the
  protected 4.2V rail that feeds the Connect Kit).
- **Top right**: test points S12TP3 (3.3V), S12TP4 (the 3.3V GPS rail) and S12TP5 (the 3.3V CAN rail).
- **Right, between the SMA connectors**: test points S12TP6 (the 3.3V K-wire rail) and S12TP7 (the 12V K-wire rail).
- **Right edge**: the GPS (top) and LTE (bottom) u.FL and SMA connectors.
- The two 20-pin Connect Kit headers run horizontally across the middle and the bottom of the
  board.

This annotated photo is of a v3.3 board, which looks the same apart from its test points and two
parts: v3.3 fits the buck under-voltage divider that is optional on v3.4, and has a MAX33041 CAN
transceiver where v3.4 specifies a TCAN3414DR. v3.3 has three test points of its own - S12TP6 and
S12TP7 on the protected and unprotected 4.2V rails, and S11TP1 for OVP fault injection - so S12TP6
and S12TP7 mean something different on the two boards.

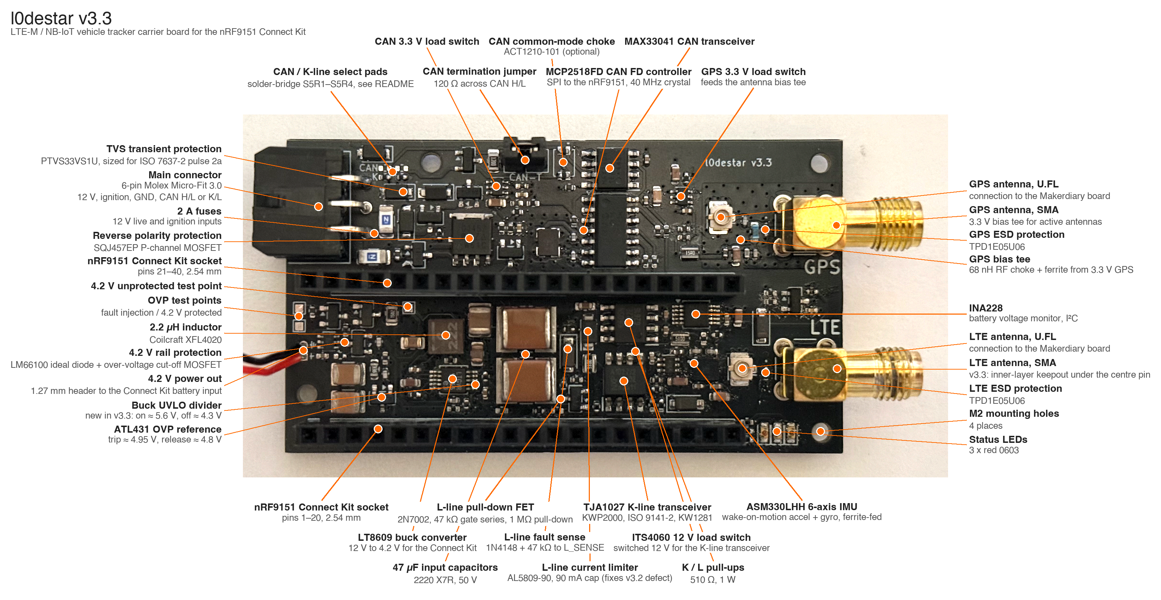
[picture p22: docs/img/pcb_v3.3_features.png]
Annotated l0destar v3.3 board


## General soldering process

There are several ways to solder SMD parts; this is the one the author finds easiest. Extra flux
is not needed - it helps little and leaves the board sticky and hard to clean.

1. Apply a very thin layer of solder paste to the pads. You probably need less than you think,
   but it does not matter much if you get it wrong.
2. Place the components with tweezers. The alignment does not need to be perfect at this point.
3. Apply hot air. The components self-align on the molten solder; nudge any that do not line up
   with tweezers.
4. Fine-pitch parts such as the LT8609A and the INA228 may end up with bridged pins. Remove the
   excess by holding the soldering iron tip against desoldering wick (MG #444) on the bridge very
   briefly - a second or two.

## Build sequence

### 1. Place the buck converter

Place the buck converter components - the S6 designators - first, and flow them into place. It is
important that the buck works and regulates correctly before anything else goes on: a fault here
can put the full input voltage on its output, which would destroy the Connect Kit.

Fit S6R4 as a 0402 0R jumper for the default build, or fit the optional enable divider (S6R4 1M,
S6R5 243K, S6R6 3.92M) if you want the buck to cut out below about 4.3V and restart above about
5.6V (calculated; a v3.3 board measured 4.47V and 5.14V). The divider adds around 9µA of sleep current at 12V; see
[component selection](component-selection.md#optional-parts).

Do **not** place the over-voltage protection stage yet - the S11 designators, including the
LM66100 ideal diode S11U1. It can also be damaged by high voltage.

### 2. Test the buck on its own

1. Solder temporary wires to a ground point (S12TP1 is convenient) and to the PP12VP net, for
   example the non-ground pad of the buck input capacitor S6C3.
2. Apply 12V, from a current-limited supply if you have one.
3. Measure the buck output on the PP4V2_UNPROTECTED net, at the non-ground pad of the output
   capacitor S6C5. It should read 4.2V.

If it reads 0V, or anything near the input voltage, stop and look for shorts or bad joints before
you continue. The protected rail test point S12TP2 reads 0V at this stage because the protection
stage is not populated yet. Remove the temporary wires afterwards.

### 3. Place the remaining SMD parts

Apply paste to the remaining pads, place the rest of the components and solder them, including the
S11 protection stage. If you are not building the CAN or K-wire interface, leave those parts off
entirely - the bill of materials lists which designators belong to each. On a CAN build without
the optional choke S9FL1, fit two 0402 0R resistors across its pads, otherwise CAN high and CAN low
are left open circuit.

### 4. Bridge the configuration pads

Bridge the pads in the top left corner for the interface you built, with solder or 0402 0R
resistors:

| Interface | S5R1 | S5R2 | S5R3 | S5R4 |
|---|---|---|---|---|
| None | OPEN | OPEN | OPEN | OPEN |
| CAN bus | CONNECT | OPEN | CONNECT | OPEN |
| K-wire | OPEN | CONNECT | OPEN | CONNECT |

!!! danger "Never connect the CAN and K pads at the same time"
    Make sure the pads that should be open really are open.

Leave S5R5, next to S11U1 at the bottom left, **open**. It bypasses the over-voltage protection
and only exists for boards built without the S11 stage, which is not recommended.

### 5. Fit the Molex connector

With all the SMD parts in place, fit the through-hole parts in order of height, starting with the
Molex Micro-Fit connector S1J1.

### 6. Fit the power lead and the termination header

Next solder the bare end of the MX1.25 power lead into S1J4, with the wire that goes to the positive
pin of its plug in the `+` hole and the other in `-`. Work out which wire is which with a meter
before you solder - see the polarity warning under [final assembly](#final-assembly). On CAN
builds, also fit the 2-pin termination header S9J1. Only fit a shunt on S9J1 if the tracker is
going to be at the end of the CAN bus. A tracker
connected to a vehicle's OBD socket normally is not, because the vehicle's bus is already
terminated.

### 7. Fit the 20-pin headers

Hold the two 20-pin headers S1J2 and S1J3 in position with tape, solder a single pin on each row to
hold them, then remove the tape and solder the rest.

### 8. Fit the SMA connectors

Do not use hot air for the SMA connectors. Fit each connector and carefully solder its pins one at a
time with the soldering iron, using no more solder than a good joint needs: excess solder can run
down a pin and short the centre pin to ground. Solder the four ground pins first and the centre pin
last. The [board test](board-test.md) checks each centre pin for a short to the
connector's outer casing.

### 9. Clean the board

Clean off paste and flux residue with isopropyl alcohol and foam swabs, inspect every joint under
magnification, and let the board dry completely before applying power - isopropyl alcohol is
highly flammable.

## Test before fitting the Connect Kit

Work through the unpowered checks and the first power-up on the
[board test](board-test.md) page now, with the Connect Kit still off the board.

## Ensure the wiring harness is connected to the power supply or vehicle correctly

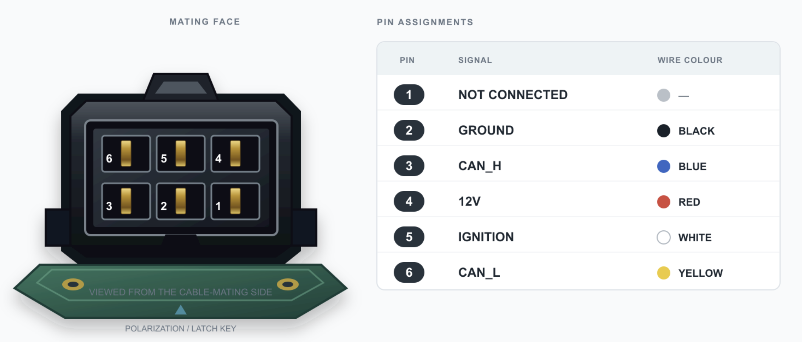
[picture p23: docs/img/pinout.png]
Pin assignments


For testing the bare minimum is 12V and ground. The ignition signal is read by
the firmware to determine if the vehicle's ignition is on but this can be
disabled or overridden.

The CAN lines can be left unconnected for bench testing or tested with a
suitable CAN adapter such as a [CANable](https://link.amazon/B0dMC3cac). Note that for testing CAN on a bench the termination jumper must be set on the l0destar board and on the CANable interface and they must have a common ground (make sure the ground pin on the CANable is connected to the same ground wire as the l0destar board).

## Final assembly

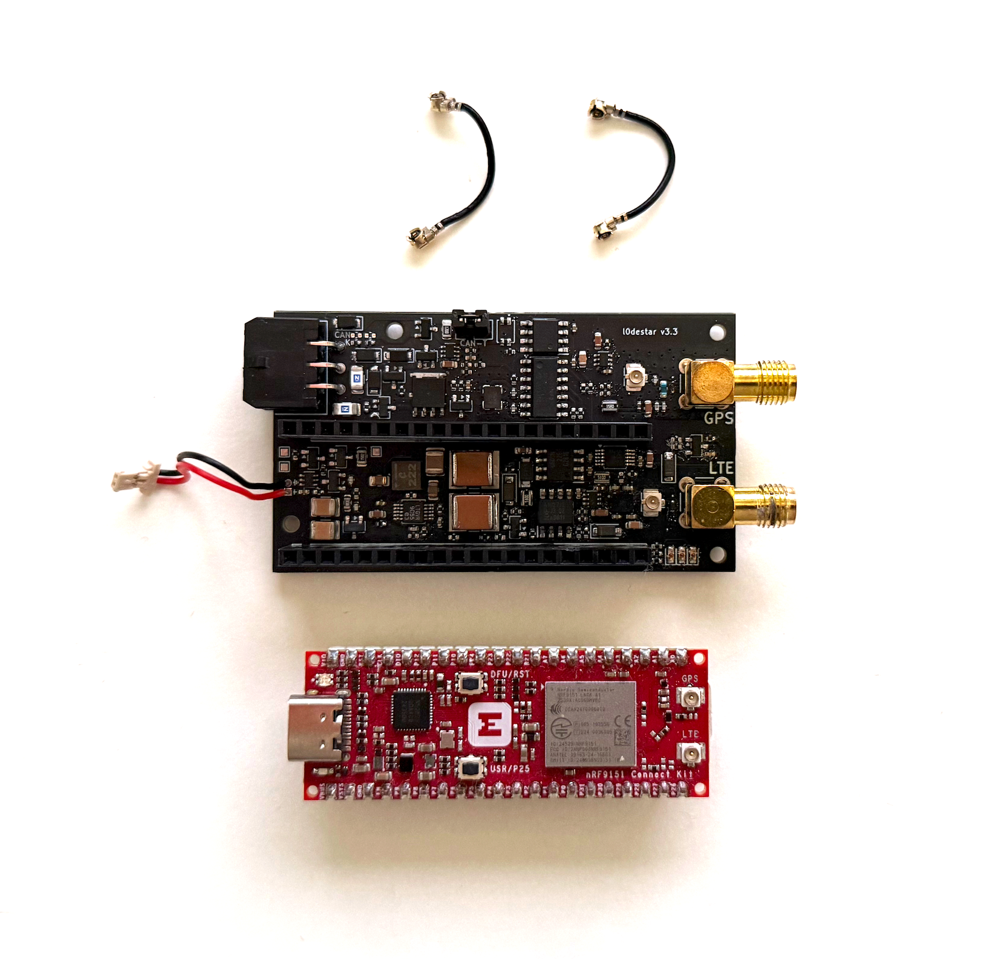
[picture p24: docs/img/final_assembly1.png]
Final assembly parts


1. Connect the LTE u.FL cable to its connector

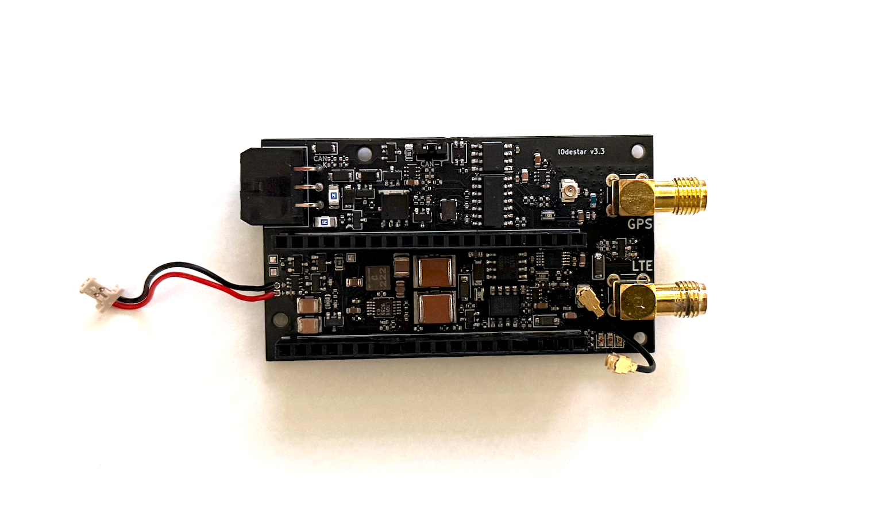
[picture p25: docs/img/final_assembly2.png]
final assembly step 1


2. Insert the SIM card into the Makerdiary Connect Kit and connect its 2-pin
power connector

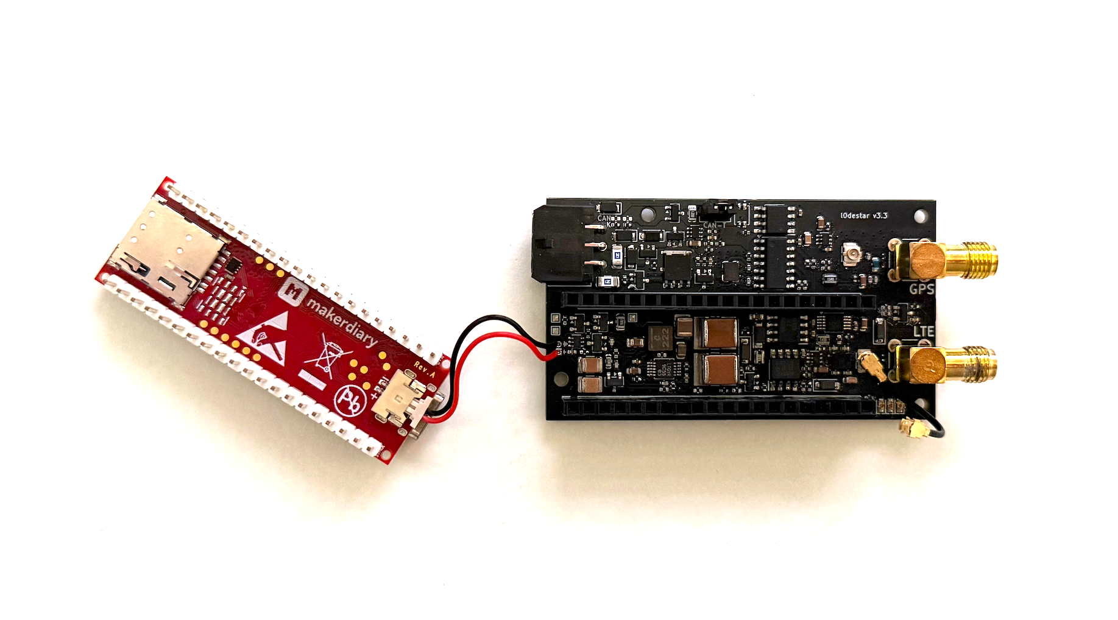
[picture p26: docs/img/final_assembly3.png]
final assembly step 2


3. Seat the Connect Kit on the 20-pin header rows ensuring the power cable
underneath is tucked inside towards the centre without being snagged

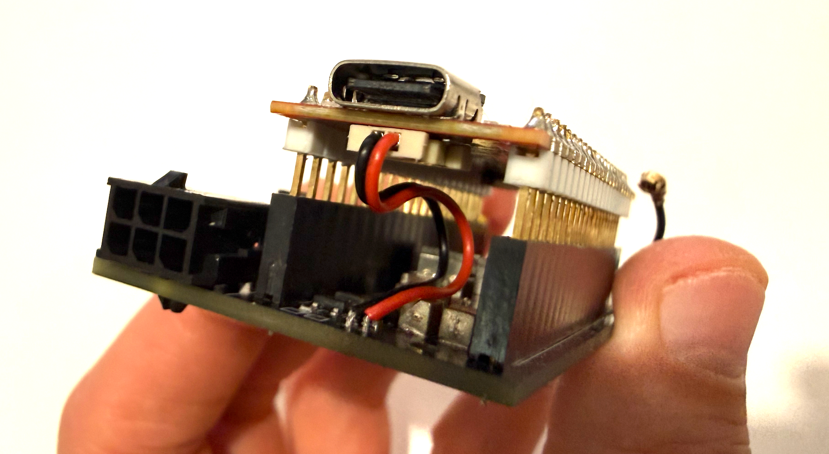
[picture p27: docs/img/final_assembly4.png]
final assembly step 3


4. Attach the GPS side u.FL connector

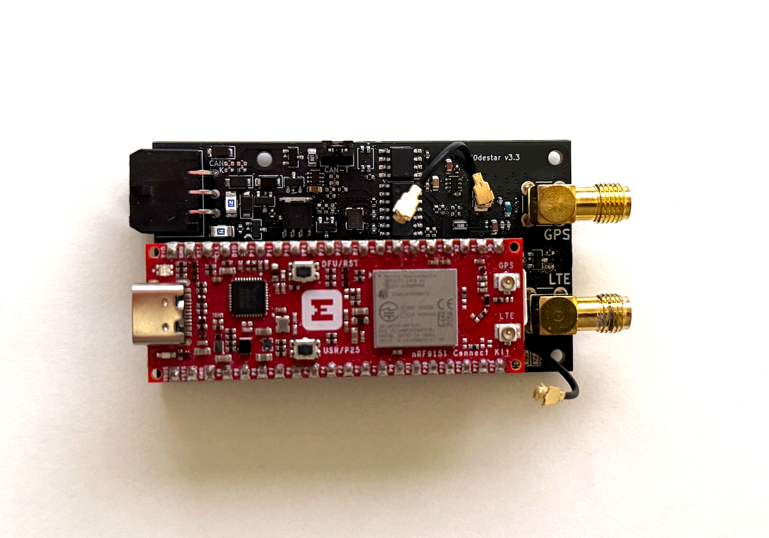
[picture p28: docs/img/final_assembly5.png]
final assembly step 4


5. Connect both u.FL connectors to the Connect Kit

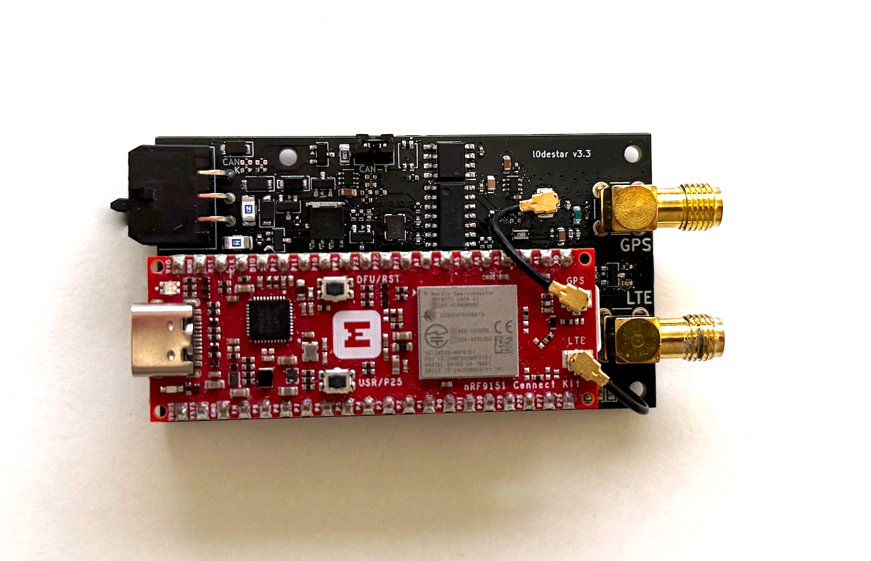
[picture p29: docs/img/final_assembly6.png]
final assembly step 5


6. Connect the two SMA connectors to your antenna. The GPS port needs an **active** antenna - see
   the [antenna requirements](../reference/hardware.md#antenna).

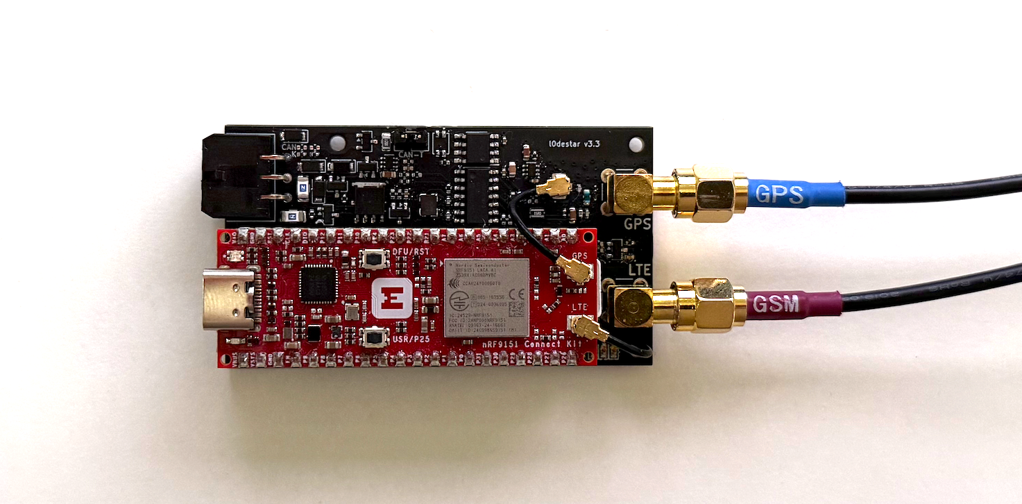
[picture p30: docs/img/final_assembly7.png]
final assembly step 6


7. Connect the wiring harness

!!! danger "Check the power lead polarity"
    Getting the power lead the wrong way round puts the 4.2V rail across the Connect Kit's
    battery input backwards. Check the lead's wiring with a meter against the markings at both
    ends before you plug it in.

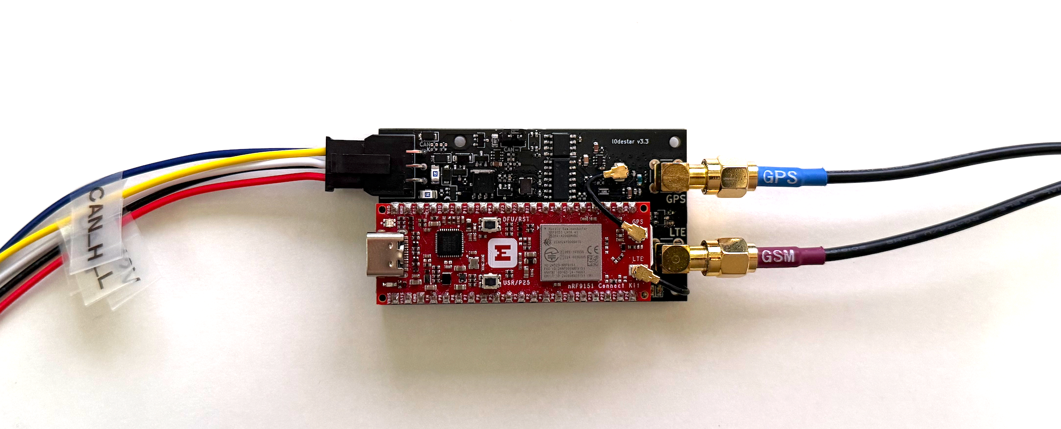
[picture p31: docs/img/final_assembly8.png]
final assembly step 7


Apply power again from the supply with the current limited to 50mA. At any sign of a short, switch
off immediately. If the current does not pin at the limit, chances are the board is built
correctly. The remaining powered checks are on the [board test](board-test.md) page.

## Enclosure

The 3D-printable enclosure in
[`hardware/enclosure/v3.3/`](https://github.com/m4rkw/l0destar/tree/master/hardware/enclosure/v3.3)
has a top and a bottom, in a variant with the l0destar logo embossed in the top and a plain one;
they are otherwise identical. It was designed for the v3.3 board, whose outline v3.4
keeps.

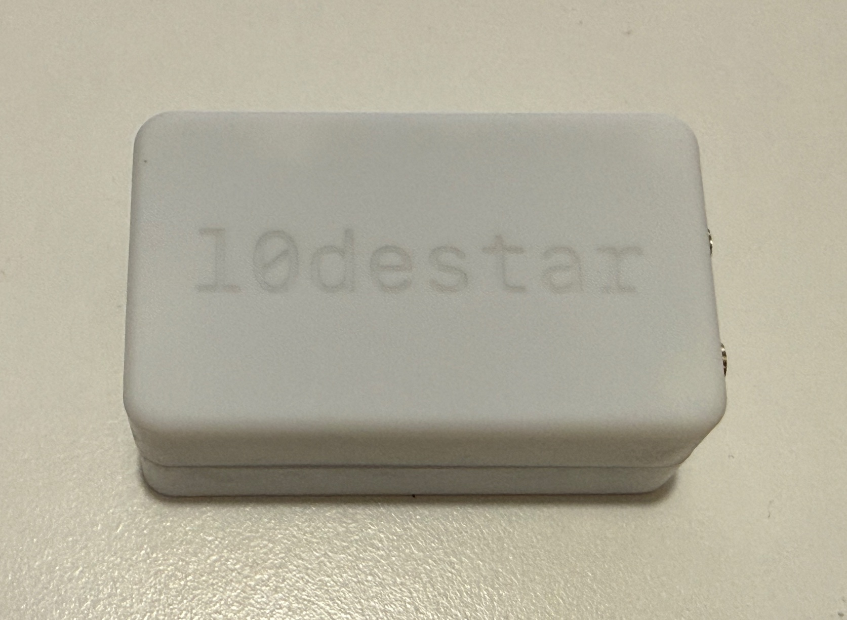
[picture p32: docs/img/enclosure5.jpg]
The printed enclosure


1. Print the top and bottom of the variant you want (`*_top.stl` and `*_bottom.stl`).
2. Press M2 heat-set inserts into the bosses with a soldering iron. Keep the iron square to the
   boss and let the insert sink under its own weight plus light pressure. Pushing too hard or too
   fast melts through the boss or leaves the insert tilted.
3. Fit the board and close the enclosure with M2 x 10mm screws. Do not over-tighten: the inserts
   will pull out of the plastic long before the screw strips.

The enclosure is a prototype. It has not been tested for mechanical strength, vibration, heat,
moisture ingress, UV exposure, flammability or vehicle temperature ranges, and the material you
print it in materially affects all of those.

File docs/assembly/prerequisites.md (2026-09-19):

# Assembly prerequisites

What you need before you start building a board: the skills, the tools, the design files, a PCB
and the parts. Which parts to buy - and which ones not to substitute - is covered on the
[component selection](component-selection.md) page.

## Skills

The board is designed to be hand-assembled at home with relatively inexpensive tools, but it is
surface mount throughout and needs hot air:

- the smallest passives are 0402;
- the finest-pitch parts are the LT8609A buck converter (MSOP-10 with an exposed pad) and the
  INA228 (VSSOP-10), where bridged pins are likely and need removing with wick;
- some parts have no exposed leads at all: the ASM330LHHX accelerometer is a 14-pad LGA and the
  antenna ESD diodes are X1SON-2 packages.

You also need to be comfortable finding a designator on the KiCad PCB and taking resistance,
continuity and voltage readings with a multimeter. If you have not soldered 0402 parts with hot
air before, practise on a scrap board first.

## Tools

These are the tools the author uses; the links are examples, not endorsements.

| Tool | Notes |
|---|---|
| Hot air rework station | e.g. [Yihua 858D](https://link.amazon/B0bN4ESzl) |
| Soldering iron | e.g. [Yihua 982](https://link.amazon/B0gqapZfV) |
| Solder paste | type 4 leaded paste is recommended, e.g. [Wonderway T4](https://link.amazon/B0hetTNxm) |
| Desoldering wick | [MG #444](https://link.amazon/B0c8qzNTj) recommended |
| Fume extraction | the author uses an [Aoyue 486+](https://link.amazon/B0alCSAYb), with a desk fan blowing the fumes towards it when using the iron |
| Bench power supply | the author uses a [Riden RD6006](https://parallaxdigital.co.uk/shop/power_supplies/bench_power_supplies/rd6006/); see below |
| Multimeter | [Fluke 117](https://link.amazon/B0g4okXV6) recommended, but any cheap meter will do |
| Tweezers | [Erem E5SA](https://link.amazon/B0aGIsvtk) recommended |
| Magnification | e.g. [USOR 15x](https://link.amazon/B0isEdLNz); a microscope is much better but costs a lot more |
| Cleaning | [isopropyl alcohol](https://link.amazon/B00urqQmb) and [foam swabs](https://link.amazon/B02K5TwZw) |

A generic 12V adapter with screw terminals, such as a
[SoulBay 30W](https://link.amazon/B0gLo8L0l), will power the board, but an adjustable bench
supply with a current limit is strongly recommended: the first power-up is done with the current
limited to 50mA so a short shows up before it does damage, and one step of the firmware board
test needs the supply voltage raised and lowered by 1V.

You will also want some tape to hold the pin headers in place while soldering them, and if you
print the enclosure, a soldering iron tip for heat-set inserts (see
[component selection](component-selection.md#enclosure-hardware)).

Before you start:

- **Buy more components than you need.** The smallest passives are 0402 and it is very easy to
  lose them or have them snap out of the tweezers.
- **Do not skimp on ventilation and fume extraction.** Solder and flux fumes can be very toxic
  and cause permanent damage.
- **Open the PCB in KiCad** so you can look up each part as you go.
- **Decide up front whether the board is CAN, K-wire or neither.** The interface parts are
  optional and there is no point placing the ones you will not use.

## Design files

Clone the repository:

```sh
git clone https://github.com/m4rkw/l0destar.git
```

The v3.4 board lives in
[`hardware/l0destar_v3.4/`](https://github.com/m4rkw/l0destar/tree/master/hardware/l0destar_v3.4):

- `l0destar.kicad_pro`, `l0destar.kicad_pcb` and one schematic sheet per subsystem;
- `libs/`, the project-local symbols, footprints and 3D models the design needs;
- `README.md`, with the bill of materials, the interface pad table, design notes and the test
  table;
- `PROTECTION.md`, the reasoning behind the 12V input protection.

The v3.4 files were saved with KiCad 10.0, so open them with KiCad 10 or later.

The enclosure is in
[`hardware/enclosure/v3.3/`](https://github.com/m4rkw/l0destar/tree/master/hardware/enclosure/v3.3):
FreeCAD sources plus STL and STEP exports of the top and bottom, with and without the l0destar
logo.

## Ordering the PCB

| Property | Value |
|---|---|
| Layers | 4 |
| Thickness | 1.6mm |
| Outline | 66.65 x 37.55mm |
| Mounting holes | 4 x M2 (2.2mm) |

- No fabrication outputs are committed for v3.4. Generate the Gerber and drill files from the
  KiCad project in the format your board house asks for.
- The RF trace widths are calculated for JLCPCB's **JLC04161H-7628** 4-layer stack-up. A
  different stack-up or fabrication process needs the widths recalculated, or the antenna feeds
  will not be the intended 50 ohms.
- Component vias are dogleg-routed deliberately, so the board needs no special via processing
  and stays cheap to make.
- Order a few spare boards. Mistakes happen, and the extra boards cost very little.

## Parts

- One [Makerdiary nRF9151 Connect Kit](https://makerdiary.com/products/nrf9151-connectkit) per
  board. It provides the modem, GNSS receiver and processor. l0destar is not affiliated with
  Makerdiary and does not sell the Connect Kit.
- The parts in the
  [v3.4 bill of materials](https://github.com/m4rkw/l0destar/blob/master/hardware/l0destar_v3.4/README.md)
  for the build you chose - see [component selection](component-selection.md).
- Two 35mm u.FL to u.FL cables and one ultra-thin MX1.25 two-pin power lead, both in the bill of
  materials. The cables link the board's u.FL connectors to the Connect Kit's antenna
  connectors; the lead takes the 4.2V rail to the Connect Kit's battery connector.
- If you are printing the enclosure: M2 heat-set inserts and M2 x 10mm screws.

An antenna, a SIM card and the firmware tooling are only needed once the board is built; they are
listed under [Board setup prerequisites](../board-setup/prerequisites.md).

## For the board test

- The current-limited bench supply and multimeter from above.
- A way to feed the board through its 6-pin Molex Micro-Fit 3.0 connector: a lead made up with
  the mating 43025-0600 housing, or temporary wires. Pin 2 is ground, pin 4 is the permanent 12V
  and pin 5 is the ignition input - see the
  [vehicle connector pinout](../reference/hardware.md#vehicle-connector-pinout). A switch in the
  ignition wire is needed for the firmware test.
- For the interactive firmware test only: a USB-C data cable, a SIM card and antenna, and the
  toolchain described in [Board setup prerequisites](../board-setup/prerequisites.md).

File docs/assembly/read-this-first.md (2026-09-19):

# Assembly: read this first

This section walks through building a l0destar carrier board by hand, from ordering the PCB to
a powered bench test. Read this page, and the project's full
[disclaimer](https://github.com/m4rkw/l0destar/blob/master/DISCLAIMER.md), before you order
anything. If you intend to fit the finished tracker to a vehicle, also read
[Deployment: read this first](../deployment/read-this-first.md).

!!! danger "Fuse both 12V inputs"
    A board wired to a vehicle battery can start a fire if it is built, wired or fused wrong.
    It is essential to fit an external 2A fuse on the permanent 12V feed **and** on the ignition
    feed. The 2A fuses on the board are a fire backstop for installations made without them, not
    a substitute for them.

## This is a prototype, not a product

- l0destar is a personal project in the prototyping and design phase. Treat every board, and
  the firmware, as unvalidated and unsafe by default.
- Nothing has been through automotive qualification, EMC testing, or formal ISO 7637-2 or
  ISO 16750 compliance testing. The protection analysis in
  [PROTECTION.md](https://github.com/m4rkw/l0destar/blob/master/hardware/l0destar_v3.4/PROTECTION.md)
  is desk work backed by datasheets - estimates and reasoning, not a test report - and the
  reasoning may be wrong.
- The design is not validated for safety-critical or security-critical use. It may fail
  silently, and it must not be anyone's only theft-recovery, safety or emergency measure.

## Which board these pages describe

These pages describe the **l0destar v3.4** board.

- **v3.4 is designed but has not yet been built or tested.** Every row of the test table in the
  [v3.4 README](https://github.com/m4rkw/l0destar/blob/master/hardware/l0destar_v3.4/README.md)
  reads NOT TESTED.
- **v3.3 is the most recent board that has been built and bench tested.** v3.4 leaves the
  accelerometer's two NC pads unconnected (they were grounded on v3.0-v3.3, which kept the part
  out of its low-power state), makes the buck converter's enable divider an optional
  part that is not fitted by default, adds test points, enlarges the holes for the Connect Kit power
  lead and specifies a TCAN3414DR CAN transceiver in place of the MAX33041E (same footprint and
  pinout).

## Test results are the author's own, and unverified

The measurements and pass/fail results quoted throughout these docs are the author's own
observations, on the author's boards, under bench conditions, with the author's instruments.
They are not independently verified. Repeat the testing yourself rather than taking them on
trust.

## Parts lists are examples, not a verified BOM

The bills of materials are suggestions. Working boards have been built with many of the listed
parts, but not necessarily from the same vendor, series or batch, and distributor links go
stale. Check every part against its current datasheet, satisfy yourself about footprint,
tolerance and voltage rating, and buy from a distributor you trust. Distributor and manufacturer
links are for identification only - they are not endorsements.

## If you build one, you are responsible for it

That means your own due diligence on part selection, assembly, fusing, wiring and installation.

- A device wired to a vehicle battery can start a fire if it is built or fused wrong.
- Anything connected to OBD or CAN can interfere with systems you want working while the
  vehicle is moving, or cause irreparable damage to very expensive computers in the car.
- 24V vehicles are not supported.

## Hazards while you build

- **Fumes.** Solder and flux fumes are toxic and can cause lasting harm. Use fume extraction and
  ventilate the room; do not skimp on this.
- **Lead.** The guide recommends leaded solder paste. Wash your hands after handling it and keep
  food and drink away from the bench.
- **Heat.** Hot air stations and soldering irons run at several hundred degrees. Work on a
  heat-resistant surface, keep flammable material away, and switch the tools off when you leave
  the bench.
- **Isopropyl alcohol** is highly flammable. Keep it away from the iron and the hot air, and let
  a cleaned board dry completely before you apply power.
- **Static.** The Connect Kit and the ICs are static sensitive. Handle boards by their edges and
  use ESD precautions.
- **First power.** Power a new board for the first time from a current-limited supply, as
  described on the [board test](board-test.md) page, and never connect the Connect Kit
  until the board has passed the checks there.

## Regulatory approval

Nothing here is CE, UKCA or FCC marked, and no conformity assessment has been carried out.
Running an LTE radio may require type approval where you live. The licences permit commercial
manufacture and sale, but anyone placing a product on the market becomes the manufacturer of
radio equipment and takes on the resulting obligations. The nRF9151's modular approval does not
transfer to a finished product.

## No warranty, no liability

No claim is made that any of this is suitable for installation in a vehicle or for any other
purpose, and no warranty is offered. All responsibility for the safety, legality and fitness for
purpose of anything built from this project rests with the person building, operating and
installing it. The full terms are in the
[disclaimer](https://github.com/m4rkw/l0destar/blob/master/DISCLAIMER.md) and
[LICENSE.md](https://github.com/m4rkw/l0destar/blob/master/LICENSE.md).

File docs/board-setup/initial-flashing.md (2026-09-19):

# Minimal firmware config and initial flashing

Build the tracker firmware for your board with the smallest configuration that reports to your server, flash it over USB, and read the device's IMEI from the console. The next page enrols the device on the server with that IMEI.

Complete [Board setup prerequisites](prerequisites.md) first. Commands on this page run in `firmware/`.

## Copy your server's CA certificate

The tracker firmware checks your server's certificate against a CA built into it when it downloads updates. Your server created that CA on its first start. Copy the certificate from it:

```sh
# in firmware/
scp tracker.example.com:/srv/l0destar/certs/ca.crt certs/ca.crt
```

The build turns it into `src/ca_cert.h`, and refuses to build the tracker firmware without it.

!!! warning "The first boot stores the CA for good"
    The first time the tracker firmware boots, it stores its CA in the modem, at security tags 1 and 42, and it never replaces a CA that is already there. A board that has once run tracker firmware built with another CA - from an earlier server, say - keeps trusting that one through every later flash, so its updates from your server fail while its telemetry works. The console then says `TLS CA already provisioned` on the very first boot. The recovery is in [firmware build options](../reference/firmware.md#the-ca-certificate). The board test and the nRF Cloud provisioning build never store the CA.

## Write local.conf

Generate the device's key:

```sh
openssl rand -hex 32
```

Then create `firmware/local.conf`, the configuration for the board on your bench, with the key in it:

```text
# firmware/local.conf

# Carrier board
CONFIG_APP_BOARD_L0DESTAR_V3_4=y
# The OBD interface you built: 0 none, 1 CAN, 2 K-wire (0 is safe on any board)
CONFIG_APP_OBD_MODE=0

# Your server, as named in its certificate
CONFIG_APP_SERVER_HOST="tracker.example.com"
# Your SIM provider's APN
CONFIG_APP_APN="your.apn"
# The key from openssl rand -hex 32
CONFIG_APP_PSK_HEX="<64 hex characters>"

# A bench unit: never replace this build over the air
CONFIG_APP_FOTA_INHIBIT=y
```

| Setting | What it does |
|---|---|
| `CONFIG_APP_BOARD_L0DESTAR_V3_4` | Selects the carrier board: its GPIO map, the parts it has and how its switched power rails are sequenced. Other revisions have their own symbol, listed in [firmware build options](../reference/firmware.md#board-selection). |
| `CONFIG_APP_OBD_MODE` | Must match the [interface selection pads](../reference/hardware.md#interface-selection-pads) you bridged: `0` none, `1` CAN, `2` K-wire. It decides which OBD rails are powered and which driver starts. `0` powers no OBD circuitry at all, so it is safe on any board while you check the rest. |
| `CONFIG_APP_SERVER_HOST` | Where telemetry (UDP 65480) and updates (TCP 65481) go. Use the name your server's certificate was issued for. It must resolve to an IPv4 address: the firmware does not use IPv6. |
| `CONFIG_APP_APN` | The default in `prj.conf` (`sensor.net`) is almost certainly not your SIM provider's APN. With the wrong APN the modem can register on the network and still have no data connection. |
| `CONFIG_APP_PSK_HEX` | The key that encrypts everything the device sends. The server gets the same key when you enrol the device. |
| `CONFIG_APP_FOTA_INHIBIT` | A bench build is version 0.4.0, older than anything published, and the firmware checks for an update every time it boots. If the server has a build published for this IMEI - a section for it in `remote.conf` - the build you are testing is replaced within seconds; a unit with no manifest is never offered one, but keep this set so a later publish cannot catch a bench unit. An image installed over the air still confirms itself with this set. Never use it in a production build; see [OTA updates](ota-updates.md). |

Everything else keeps its default. [Firmware build options](../reference/firmware.md) lists every setting, including `CONFIG_APP_SERVER_PORT` and `CONFIG_APP_FOTA_PORT` for a server that publishes its ports under other numbers.

!!! tip "Recording the console"
    `CONFIG_APP_DEMO_MODE=y` replaces coordinates with a placeholder in everything printed on the console, so a live unit can be shown on screen without revealing where it is. What goes to the server is unchanged.

## Build

```sh
# in firmware/
./build.sh
```

The first build also sets up what the firmware needs from your machine:

```text
Version: 0.4.0
Board profile: makerdiary  (target: nrf9151_connectkit/nrf9151/ns)
Fetching the Connect Kit board definition from makerdiary/nrf9151-connectkit
Creating the firmware signing key: /home/you/l0destar/firmware/mcuboot_priv.pem
Back it up somewhere safe: boards flashed from now on only install updates signed with it.
src/ca_cert.h updated from certs/ca.crt
...
Built: /home/you/l0destar/firmware/build/merged.hex  (profile: makerdiary, target: nrf9151_connectkit/nrf9151/ns)
```

!!! warning "Back up mcuboot_priv.pem"
    Firmware updates are signed with this key, and the bootloader on every board you flash installs only images signed with it. Lose it and none of those boards can be updated over the air again: each would need reflashing through its USB port. Anyone who has it can build firmware your boards will install. Keep a copy somewhere offline. It is gitignored.

- `build/merged.hex` is the bootloader and firmware together, for flashing over USB. `build/firmware/zephyr/zephyr.signed.bin` is the signed image an over-the-air update uses.
- A build on the bench is always version 0.4.0. Only `push_fw.sh` gives builds a patch number.
- `./build.sh pristine` forces a clean build.

| Build error | Cause |
|---|---|
| `LOCAL_CONF=local.conf not found` | There is no `local.conf` in `firmware/`. |
| `certs/ca.crt not found` | Copy your server's CA certificate first, as above. |
| `nRF Connect SDK v3.3.0 is not in /opt/nordic/ncs or ~/ncs` | The SDK is somewhere else: set `NCS_ROOT` to its directory. |
| `Aborting due to Kconfig warnings` | A line in `local.conf` names a symbol that does not exist, or a value out of range. The warning just above names the line. |

## Flash

If the bench supply's current limit is still at the 50mA used for the first power-up checks, raise it to around 300mA now. From here on the modem registers and transmits, averaging up to about 45mA from the 12V input at full transmit power with bursts above that, and a supply that hits its current limit makes the board brown out and reset.

With the Connect Kit connected over USB - the 12V supply can stay on:

```sh
# in firmware/
./flash.sh
```

`flash.sh` programs the board with pyocd and then pulses the reset line. That reset also restarts the Connect Kit's USB interface, so the serial ports disappear and come back: reopen your console afterwards.

A board that has been running other firmware may have its debug access locked. pyocd then erases the chip to unlock it, which prints `APPROTECT enabled: will try to unlock via mass erase`, and the first attempt can stop with `Memory transfer fault` just after the erase. `flash.sh` notices, says so and loads the firmware again, which programs the board. It only tries again in that case: any other failure stops it straight away. The erase only covers the application: the modem's firmware and everything stored in the modem survive it.

This first flash also puts the MCUboot bootloader on the board, which is why it has to be done through the probe: a board can only update itself over the air once it has a bootloader.

To restart the firmware without flashing it again:

```sh
./reset.sh
```

`reset.sh` pulses the reset line, like `flash.sh`, so the serial ports disappear and come back: reopen your console afterwards.

### Why the scripts reset the way they do

- Programming normally ends with a soft reset, but that leaves the nRF9151 in debug interface mode, where it draws milliamps while asleep until the next pin reset or power cycle. `flash.sh` and `reset.sh` use a pin reset instead.
- After a pin reset the chip's access port protection (APPROTECT) is armed again. The firmware clears it on every boot, but only while the chip's UICR register allows it. pyocd's default answer to a protected chip is a mass erase, which wipes the firmware and that register - and a board in that state erases itself again on its next reset. So both scripts tell pyocd not to erase when resetting. The programming step in `flash.sh` is the one place an erase is allowed, because it rewrites the register and the firmware straight afterwards.
- If `./reset.sh` fails and pyocd mentions APPROTECT, run `./flash.sh`. That is the recovery.

## Watch the console

The console is the first of the Connect Kit's two serial ports, at 115200 baud (8N1). On macOS, list the ports and open the first:

```sh
ls /dev/cu.usbmodem*
screen /dev/cu.usbmodemXXXX 115200
```

macOS resets a serial port to 9600 baud whenever it is opened, so use a terminal like `screen` that holds the port open. Install it from Homebrew or MacPorts if `screen` is not on your path.

On Linux the console has a fixed name. Install `screen` with `sudo apt install -y screen` if you do not have it, then:

```sh
screen /dev/serial/by-id/usb-Makerdiary_IFMCU_CMSIS-DAP_*-if00 115200
```

Leave `screen` with Ctrl-A then K. `screen -L` also records everything to `screenlog.0`. `./reset.sh` restarts the Connect Kit's USB as well, so reopen the console straight after it; the first lines of the boot can be missed.

A healthy boot looks like this (abridged - timings and readings will differ):

```text
*** Booting MCUboot v2.3.0-dev-fce4dac2e629 ***
*** Booting My Application v0.4.0 ***
<inf> main: === l0destar firmware boot (v0.4.0, board v3.4+kline) ===
<inf> main: reset cause: pin
<inf> settings: apn=your.apn user=
<inf> settings: imei=(unset)
<inf> hw_selftest: === power rail self-test ===
<inf> hw_selftest: self-test: all rails OK
<inf> main: ignition=OFF battery=12.01V
<inf> modem: init ok
<inf> main: imei=350000000000000
<inf> modem: TLS CA provisioned (sec_tag 1)
<inf> modem: FOTA CA provisioned (sec_tag 42)
<inf> modem: connecting (this can take 30s+)...
<wrn> lte_lc: Registration rejected, EMM cause: 15, Cell ID: 366868, Tracking area: 12296, LTE mode: 7
<inf> modem: nw reg status: 5
<inf> modem: connected
<wrn> fota: updates inhibited (APP_FOTA_INHIBIT) — running 0.4.0
<inf> modem: PLMN: mcc=234 mnc=30
<inf> transport: sent 552 bytes
```

What to look for:

- **`board v3.4+kline`** - the board and interface you configured (`+can` for CAN, nothing after the version for no interface).
- **`self-test: all rails OK`** - the switched rails came up. `RAIL:` or `SELFTEST:` failures send you back to the [board test](../assembly/board-test.md).
- **`battery=`** close to your supply voltage, and **`ignition=`** following the switch on pin 5.
- **`imei=`** straight after `init ok`. Write the IMEI down: you need it on the next page.
- **`connected`** - the modem has registered on the network.
- **`sent N bytes`** - a datagram went to your server. A record needs a position, so nothing is sent until the GNSS antenna has had its first fix since the tracker started: `no fix, skipping send` means it is still waiting.
- With pin 5 off, **`entering sleep`** a few seconds later. The `registration lost (status 0)` warning after `sleep: modem power off` is the modem being switched off, not a fault.

A roaming SIM often sees a few `Registration rejected` warnings from networks it may not use before `nw reg status: 5` (registered, roaming) - that took about 50 seconds on the author's bench. The two `CA provisioned` lines appear on the tracker firmware's first boot only; later boots, and boards that already hold a CA, print `TLS CA already provisioned (sec_tag 1)`.

### No connected line

The modem has not registered within a minute of starting. The firmware leaves it searching and carries on as soon as it registers. If it never connects, check that the SIM is inserted and active, the APN, that the antenna is on the LTE connector and that there is LTE-M coverage, then `./reset.sh`.

### Expected at this stage

The server does not know the device yet, so it drops what the device sends: its `udp.log` shows `decrypt failed from <address>`, and the console never prints a `resp:` line. Enrolling the device on the next page fixes that, without building or flashing again.

## How it behaves on the bench

These are worth knowing when you check telemetry later:

| Bench state | What the firmware does |
|---|---|
| Pin 5 off (ignition off) | Sends a record, then sleeps. It wakes on ignition, movement, knocks and tilt, and every 15 minutes until the server has told it how often to report. Without a fix since it started it sends nothing and sleeps, then looks for a fix again on timed wakes: after 15 and 30 minutes, 1, 2 and 4 hours, then every 4 hours. |
| Pin 5 on, supply below 13.0V | Ignition on with the engine stopped: sends a record about every 30 seconds and reads the server's reply each time. |
| Pin 5 on, supply at 13.0V or above | The engine counts as running: it tracks continuously and sends three records per datagram. |

Once the engine counts as running, the supply has to stay below 13.0V for five minutes, with GNSS showing no movement, before the firmware treats it as stopped again.

## Troubleshooting

| Symptom | Check |
|---|---|
| `pyocd list` finds no probe | The cable carries data. On Linux, the udev rule from the [prerequisites](prerequisites.md#linux-access-to-the-connect-kit) is in place. In a virtual machine, the Connect Kit is connected to it. |
| `flash.sh` stops with `Memory transfer fault` | Unplug USB and power the board off and on, then run `./flash.sh` again. |
| Permission denied opening the serial port | On Linux, you are in the `dialout` group and have logged in again since adding it. |
| The board keeps restarting | The bench supply's current limit: around 300mA once firmware is running, because the modem's transmit bursts can take a 50mA supply into its limit and brown the board out. Then look for a pattern in the `reset cause:` line. |
| `RAIL:... fail` or `SELFTEST:` messages | A switched rail did not come up: go back to the [board test](../assembly/board-test.md). |
| `no GPS fix` | Active antenna on the GNSS connector, with a view of the sky. An unassisted first fix can take 2 to 5 minutes. |
| `no fix, skipping send`, and no `sent` line | Nothing is sent before the first GNSS fix since the tracker started. Check the antenna as above, then switch pin 5 on: with the ignition on it keeps searching until it has a fix. |
| `battery=0.00V` or a silly reading | 12V on pin 4, and the INA228 stage of the board test. |

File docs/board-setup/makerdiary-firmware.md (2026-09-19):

# Updating the Makerdiary firmware

The Connect Kit has a second microcontroller, an nRF52820, that runs its USB connection and acts as the debug probe. Its stock firmware leaves a high-frequency clock running after the USB cable is unplugged, which costs about 2mA continuously - more than fifty times the tracker's whole sleep budget of roughly 35.5µA. On a vehicle battery that is the difference between weeks of standby and days.

The fix is in the Makerdiary repository in two parts: [#19](https://github.com/makerdiary/nrf9151-connectkit/pull/19) puts the nRF52820 into SYSTEM OFF when USB is unplugged, and [#20](https://github.com/makerdiary/nrf9151-connectkit/pull/20) does the same on the two other power-off paths, without which the chip can still hang at about 2mA. Both are merged into `main`, but at the time of writing no Makerdiary release contains them: v2.0.0, every prebuilt image and the Connect Kits currently shipping all predate the fix. Build the firmware from source and flash it once on every Connect Kit before it goes into a vehicle. `flash.sh` only programs the nRF9151 and never touches this chip.

There is more background in the [original write-up](https://l0destar.com/blog/makerdiary-nrf52820-firmware-bug.html).

## Install nRF Connect SDK v3.4.0

The interface firmware builds with nRF Connect SDK v3.4.0, alongside the v3.3.0 the tracker firmware uses.

**With nRF Util** (macOS, or Linux on x86_64):

```sh
nrfutil sdk-manager install v3.4.0
```

**On Linux on arm64**, install it the way the [prerequisites](prerequisites.md#nrf-connect-sdk) install v3.3.0, with the Zephyr SDK that v3.4.0 needs, 1.0.1. It takes about another 4.5GB:

```sh
uvx --python 3.12 west init -m https://github.com/nrfconnect/sdk-nrf --mr v3.4.0 ~/ncs/v3.4.0
cd ~/ncs/v3.4.0
uvx --python 3.12 west update --narrow -o=--depth=1
uv venv --python 3.12 .venv
uv pip install --python .venv/bin/python west -r zephyr/scripts/requirements.txt -r nrf/scripts/requirements.txt -r bootloader/mcuboot/scripts/requirements.txt

cd ~
wget https://github.com/zephyrproject-rtos/sdk-ng/releases/download/v1.0.1/zephyr-sdk-1.0.1_linux-aarch64_minimal.tar.xz
tar xf zephyr-sdk-1.0.1_linux-aarch64_minimal.tar.xz && rm zephyr-sdk-1.0.1_linux-aarch64_minimal.tar.xz
zephyr-sdk-1.0.1/setup.sh -t arm-zephyr-eabi -c
```

## Build

```sh
# in firmware/
ifmcu/build.sh
```

The script builds Makerdiary's repository, unmodified, from the copy your first tracker build fetched into `ifmcu/.makerdiary-repo` (it clones the repository itself if that is missing), taking the board definition from the same copy. Set `NCS_VERSION` or `NCS_ROOT` if your SDK is elsewhere.

It refuses to build a clone that doesn't include #20, or that has local changes - an older `ifmcu/build.sh` patched the clone itself, and that patch made a clone from before #20 look fixed. Discard any changes, update the clone and run the script again:

```sh
git -C ifmcu/.makerdiary-repo checkout -- .
git -C ifmcu/.makerdiary-repo pull
```

The image is written to `build_ifmcu/ifmcu_firmware/zephyr/zephyr.uf2`.

## Flash

1. If the Connect Kit is on the carrier board, switch off the 12V supply: the board powers the Connect Kit through its battery connector, so plugging in USB would not restart it.
2. Unplug USB, hold the DFU/RST button on the Connect Kit, plug USB back in and then release the button. A drive called `UF2BOOT` appears. (Pressing the button while the Connect Kit is running only resets the nRF9151.)
3. Copy the image onto it.

On macOS:

```sh
# in firmware/
cp build_ifmcu/ifmcu_firmware/zephyr/zephyr.uf2 /Volumes/UF2BOOT/
```

On a Linux desktop, the drive is mounted where your desktop puts removable drives, usually `/media/$USER/UF2BOOT`:

```sh
# in firmware/
cp build_ifmcu/ifmcu_firmware/zephyr/zephyr.uf2 /media/$USER/UF2BOOT/
```

The Connect Kit resets by itself when the copy completes.

!!! tip "Working in a virtual machine"
    In bootloader mode the Connect Kit is a different USB device, a drive rather than a probe, so the virtual machine has to be given that device too.

## Check it took

1. Remove every other supply: if the Connect Kit is on the carrier board, switch off the 12V bench supply.
2. Unplug USB.

With the fixed firmware the RGB LED goes completely dark and the Connect Kit's draw falls to microamps. With the stock firmware the nRF52820 stays awake at about 2mA, sometimes with the green LED still lit.

Once the tracker firmware is running, the whole board asleep at 12V should draw tens of microamps. A board sitting a couple of milliamps above that after USB has been unplugged has not taken this update.

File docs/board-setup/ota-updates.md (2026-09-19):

# OTA updates

l0destar devices update themselves over the air from your server. Nothing is pushed: you publish a build, each device notices the next time it hears from the server, downloads it and installs it with the MCUboot bootloader, which puts the old firmware back if the new one does not start.

Every device gets its own build. Boards differ in revision and in which OBD interface is fitted, and MCUboot only checks that an image is signed, not that it suits the hardware - an image built for another board installs cleanly and then misbehaves. So the fleet is described device by device, and a device the server has no build for is never offered one.

## How an update reaches a device

1. You run `push_fw.sh` on your build machine. For each device in `remote.conf` it builds an image, uploads it to the server's firmware directory as `l0destar-<version>-<imei>.bin` and writes that device's `manifest-<imei>.txt`.
2. From then on, every reply the server sends that device carries `fota=<version>`, and the device compares it with the version it is running.
3. When the published version is newer, the device checks for the update at the next safe moment: from its main loop while the engine is not running, on a timed engine-off wake, or on the way to sleep when the ignition is switched off. It also checks every time it boots, and when it is sent the `fota` command.
4. It fetches `/fw/manifest.txt?imei=<imei>&v=<running version>` from `CONFIG_APP_SERVER_HOST` on TCP port 65481 over TLS, checking the server's certificate against the CA stored in its modem. It installs only a strictly newer version whose `board=` matches its own build (for example `v3.4+kline`), and waits while the vehicle battery reads below 12.0V.
5. It raises the alert `fota: <old> -> <new> available, downloading`, stops GNSS (which shares the radio front end) and downloads the image into its second flash slot in 2KB pieces: up to three attempts per check, within a 20 minute budget.
6. It tells the server the image is staged, raises `fota: <old> -> <new>, rebooting` and restarts.
7. MCUboot swaps the new image in as a trial. The new firmware runs its whole start-up and then confirms itself. An image that hangs or crashes before that is swapped back out on the next boot.
8. The server sees the new version when the device next checks in and sends `<name>: fota: updated to <version>`. If MCUboot put the old image back instead, the server sends `<name>: fota: <version> failed to boot (running <old>) — updates withheld until retried` and stops offering that version to that device.

A failed download is retried after 10 minutes, doubling up to 80 minutes. Once a version has failed to boot on a device, the server stops offering it to that device, and the device refuses it itself after a second failure, until you [retry it](#when-an-update-fails). A newer version is always offered.

## What you need

- TCP port 65481 on the server reachable from the internet. The Docker installation sets up the TLS listener itself; see [telemetry port](../server/telemetry-port.md).
- Devices whose modems trust your CA: built with your server's CA from their very first boot, as in [minimal config and initial flashing](initial-flashing.md#copy-your-servers-ca-certificate).
- SSH access from your build machine to the server as the owner of `/srv/l0destar`, who can write to its firmware directory, `/srv/l0destar/fw`. See [server deployment](../server/deployment.md).
- `firmware/certs/ca.crt`, your server's CA certificate. `push_fw.sh` uses it to check the endpoint the way a device will.
- `firmware/mcuboot_priv.pem`, the signing key your first build created. Every build for every device must be signed with the same key for as long as the devices are in service.
- curl, ssh and scp. `push_fw.sh` runs on macOS and Linux.
- Each device's IMEI, and the key it was [enrolled](server-onboarding.md) with.

## Describe your devices in remote.conf

`firmware/remote.conf` lists the devices in the field, one section per IMEI. It is gitignored because it holds their keys - back it up along with the signing key. Start from the example:

```sh
# in firmware/
cp remote.conf.example remote.conf
```

Then replace the contents with your own devices:

```ini
[common]
CONFIG_APP_SERVER_HOST="tracker.example.com"
CONFIG_APP_APN="your.apn"
CONFIG_LTE_NETWORK_MODE_LTE_M_GPS=y

[350000000000000]
name    = Car
profile = makerdiary
CONFIG_APP_BOARD_L0DESTAR_V3_4=y
CONFIG_APP_OBD_MODE=2
CONFIG_APP_PSK_HEX="<64 hex characters>"
```

- `[common]` applies to every device. Each IMEI section is layered on top of it and wins.
- Lower-case `key = value` lines are for the script: `name` labels the device in its output, `profile` is `makerdiary` for the Connect Kit (or `dk` for Nordic's development kit), and `board` names a Zephyr board target explicitly, which is rarely needed.
- `CONFIG_` lines are copied verbatim into that device's configuration fragment, `.remote/<imei>.conf`.
- `local.conf` is never included, so nothing from your bench reaches a device in the field.
- Set the APN here: the example does not, and a production build would otherwise get the `prj.conf` default.
- If your server publishes its ports under other numbers, put `CONFIG_APP_SERVER_PORT` and `CONFIG_APP_FOTA_PORT` in `[common]` too, and set `VERIFY_PORT` to the update port when you run `push_fw.sh`.
- The options a vehicle build needs, such as K-wire telemetry and alert priorities, are covered in [deployment configuration](../deployment/configuration.md).

!!! warning "One key per device"
    The example puts `CONFIG_APP_PSK_HEX` in `[common]`, which would give every device the same key. Put each device's key - the one it was enrolled with - in its own section.

!!! warning "Never inhibit updates in remote.conf"
    A device built with `CONFIG_APP_FOTA_INHIBIT=y` never updates again, and `push_fw.sh` does not check for it. Keep that setting in `local.conf`.

## Publish a release

Tell the script where the server keeps its firmware, check what it is about to do, then publish:

```sh
# in firmware/
export FW_SERVER=you@tracker.example.com
export FW_DIR=/srv/l0destar/fw
./push_fw.sh --list
./push_fw.sh
```

`FW_SERVER` is the SSH destination and `FW_DIR` the firmware directory on the server. The script stops without `FW_SERVER`; `FW_DIR` defaults to `/srv/l0destar/fw`, the Docker installation's. The script takes the hostname to verify against from `CONFIG_APP_SERVER_HOST` in `[common]`.

`--list` prints the version it would publish and each device's resolved configuration without building anything. Then, for each device, `push_fw.sh`:

1. Writes the device's configuration fragment and builds it into `build_remote_<imei>/`.
2. Refuses to publish a build whose version does not match the release, a version that is not newer than the one the device is already offered (unless `--force`), or a build with a bench override left on - `APP_DEBUG_IGNITION`, `APP_DEBUG_BATTERY_MV`, `APP_CAN_TEST`, `APP_KLINE_TEST` or `APP_ACCEL_TEST`.
3. Uploads the signed image, then replaces the manifest in one step, so a device fetching in the middle sees either the old release or the new one.
4. Checks the result the way the device will: the manifest through `?imei=` over TLS on port 65481, trusted by your CA, and a ranged request for the image answered with `206`.

It finishes like this:

```text
done: 1 device(s) will pull 0.4.13 on their next telemetry
      exchange or power-on
```

| Option | Effect |
|---|---|
| `--device <imei>` | Build and publish only that device. |
| `--list` | Show the next version and each device's configuration; publish nothing. |
| `--no-build` | Publish the images already in `build_remote_*/`. |
| `--force` | Allow a version that is not newer than the live one. |
| `--patch <n>` | Use this patch number instead of working it out. |

### Version numbers

`firmware/VERSION` holds only the major and minor version (`0.4`). The patch number is worked out from what your server has already published - it lists every version it holds at `/fw/published.txt` - plus one, so there is nothing to bump by hand, and machines publishing one after another never reuse a number (nothing stops two publishing at the same moment). The first release of a minor version is patch 1: patch 0 is what every bench build gets, and a device only installs a version newer than the one it runs. If that list cannot be fetched, the script stops rather than guess.

Devices install only strictly newer versions, and each part of the version runs from 0 to 255. When the patch number would pass 255, raise the minor version in `VERSION` (for example to `0.5`) and patches start again from 1. To roll a device back, check out the old code but keep the current `VERSION` file, or raise it, then publish: the old code goes out under the next number. With its own, older `VERSION` it would build a version the device will not install, and `push_fw.sh` refuses it.

## Watching an update

A device learns about an update the next time it reads a reply from the server: within about 30 seconds when its ignition is on, and while driving. A parked device that makes no timed wakes learns at its next journey, and normally installs the update when the ignition is switched off. The [device settings reference](../reference/device-settings.md) lists when replies are read.

As it happens you get, in order:

- `<name>: fota: 0.4.12 -> 0.4.13 available, downloading` from the device.
- `<name>: fota: 0.4.12 -> 0.4.13, rebooting` from the device.
- `<name>: fota: updated to 0.4.13` from the server.

On the server, `tls.log` shows the manifest request and the first and last ranges of the download, and the transport logs record the device staging the version and then `... is running 0.4.13 — update confirmed`. The version each device runs is shown in the web interface's device list and stored with every record.

## When an update fails

| What you see | What happened | What to do |
|---|---|---|
| `fota: <old> -> <new> failed after <n> attempts (err <e>, cause <c>)` | The download did not complete. | Check TCP 65481 is reachable from outside and the certificate is valid. The device retries by itself; the `fota` command retries now. |
| `<name>: fota: <version> failed to boot (running <old>) — updates withheld until retried` | The image installed but did not start, and MCUboot reverted it. | Publish a fixed, newer version (offered automatically), or retry the same one with `command.py <imei> fota-retry`. |
| Console: `manifest targets board '...', this unit is '...' — refusing` | The device's section in `remote.conf` does not match its hardware. | Correct the section and publish again. |
| Console: `battery ... — deferring update` | The vehicle battery reads below 12.0V. | Nothing: it tries again at the next check. |
| Console: `manifest request failed` while telemetry works | The TCP path to port 65481 is broken - working UDP telemetry proves nothing about TCP - or the modem trusts a different CA. | Check port 65481 is forwarded and open; a failed connection often reports error 22 (EINVAL) rather than a timeout. If the board ever booted the tracker firmware with another CA, the recovery is in [firmware build options](../reference/firmware.md). |

To retry a version the server is withholding, run on the server:

```sh
sudo docker exec l0destar python tools/command.py 350000000000000 fota-retry
```

That clears the server's block and queues the `fota` command, which clears the device's own block and makes it check at the next reply it reads.

## Bench units

- Build bench units with `CONFIG_APP_FOTA_INHIBIT=y`, as in [minimal config and initial flashing](initial-flashing.md). The unit skips the check at boot, ignores update adverts, and answers the `fota` command with `fota: updates inhibited`.
- Never use `CONFIG_APP_FOTA=n` instead. That also removes the call that confirms an image, so a build that did arrive over the air would be reverted on its next boot.
- Keep bench units out of `remote.conf`. A device with no manifest on the server is never offered anything.

A unit running an inhibited bench build never fetches an update, so to move it into the fleet add its section to `remote.conf`, publish it, then flash that same image over USB once:

```sh
# in firmware/
./push_fw.sh --device 350000000000000
pyocd load -t nrf91 --no-reset build_remote_350000000000000/merged.hex
pyocd reset -t nrf91 -m hw -O auto_unlock=false
```

## Security

!!! warning "Images contain the device's key"
    `CONFIG_APP_PSK_HEX` is compiled into each image, and the server's TLS port serves images to anyone who can reach it and knows the device's IMEI. Read [server security](../server/security.md) before leaving TCP 65481 open permanently.

The signing key is the other half: anyone holding `mcuboot_priv.pem` can build firmware every one of your devices will accept. Keep it offline and backed up.

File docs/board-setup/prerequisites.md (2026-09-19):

# Board setup prerequisites

This section brings one board up on the bench - flashed with the tracker firmware, enrolled on your server and reporting - before it goes anywhere near a vehicle.

The shortest way to a working tracker is the first four pages: this one, [minimal config and initial flashing](initial-flashing.md), [onboarding the device into the server](server-onboarding.md) and [verifying telemetry](verifying-telemetry.md). The pages after them cover the web interface, over-the-air updates, the Makerdiary firmware update every Connect Kit needs before it goes into a vehicle, and the optional nRF Cloud onboarding. Once a board is reporting, [firmware build options](../reference/firmware.md) lists everything you can change.

It assumes a board that has been through [Assembly](../assembly/board-test.md) and a server installed as described in [Server installation](../server/installation.md). The interactive stage of the board test needs the software on this page, so if you have not run it yet, come back to it once this page is done.

## Hardware

- **The assembled carrier board** with the Makerdiary nRF9151 Connect Kit fitted, the u.FL leads connected, and the unpowered and first power-up checks from the [board test](../assembly/board-test.md) passed.
- **A USB-C data cable.** A charge-only cable powers the Connect Kit but never shows up as a debug probe.
- **A current-limited 12V bench supply.** The 50mA limit is only for the first power-up checks. Before running firmware, raise it to around 300mA: a modem transmitting at full power averages up to about 45mA from the 12V input, with bursts above that, and a supply that hits its current limit makes the board brown out and reset.
- **A bench lead** for the board's Micro-Fit 3.0 connector (pinout in the [hardware reference](../reference/hardware.md#vehicle-connector-pinout)): ground on pin 2, 12V on pin 4 (permanent live), and 12V through a switch on pin 5 so you can turn the ignition on and off. Leave pins 1, 3 and 6 unconnected on the bench.
- **An antenna** that meets the [antenna requirements](../reference/hardware.md#antenna). The GNSS port needs an active antenna. Put it by a window or outside: GNSS will not get a fix in the middle of a room.
- **A SIM card that supports LTE-M**, activated, and the APN its provider tells you to use. The firmware only uses LTE-M - NB-IoT is disabled in `prj.conf` - so a SIM or network without LTE-M never registers.
- **Your l0destar server**, installed and reachable from the internet on UDP 65480 and TCP 65481 ([Telemetry port](../server/telemetry-port.md)).

## Software

The build and flash scripts run on macOS and Linux.

### nRF Connect SDK

The tracker firmware builds with nRF Connect SDK v3.3.0.

**On macOS, or Linux on an x86_64 machine,** install [nRF Util](https://www.nordicsemi.com/Products/Development-tools/nRF-Util), then let it install the SDK and its toolchain:

```sh
nrfutil install sdk-manager
nrfutil sdk-manager install v3.3.0
```

It puts the SDK in `/opt/nordic/ncs/v3.3.0` on macOS and `~/ncs/v3.3.0` on Linux, which is where the build script looks for it.

**On Linux on an arm64 machine** - a Raspberry Pi, or a virtual machine on an Apple silicon Mac - Nordic publishes no toolchain for nRF Util to install, so install the SDK with west and the Zephyr SDK instead. These commands were tested on Ubuntu 26.04, and use about 5GB:

```sh
sudo apt install -y git cmake ninja-build gperf device-tree-compiler xz-utils file make gcc g++ libmagic1 wget
curl -LsSf https://astral.sh/uv/install.sh | sh
```

Open a new shell so that `uv` is on your path, then:

```sh
uvx --python 3.12 west init -m https://github.com/nrfconnect/sdk-nrf --mr v3.3.0 ~/ncs/v3.3.0
cd ~/ncs/v3.3.0
uvx --python 3.12 west update --narrow -o=--depth=1
uv venv --python 3.12 .venv
uv pip install --python .venv/bin/python west -r zephyr/scripts/requirements.txt -r nrf/scripts/requirements.txt -r bootloader/mcuboot/scripts/requirements.txt

cd ~
wget https://github.com/zephyrproject-rtos/sdk-ng/releases/download/v0.17.4/zephyr-sdk-0.17.4_linux-aarch64_minimal.tar.xz
tar xf zephyr-sdk-0.17.4_linux-aarch64_minimal.tar.xz && rm zephyr-sdk-0.17.4_linux-aarch64_minimal.tar.xz
zephyr-sdk-0.17.4/setup.sh -t arm-zephyr-eabi -c
```

The build script finds this installation by itself: it uses the `west` in `~/ncs/v3.3.0/.venv` whenever nRF Util has no toolchain for the version. `--depth=1` fetches only the SDK's current source, not its history.

### pyocd

pyocd flashes the board through the Connect Kit's debug probe. Install it with [uv](https://docs.astral.sh/uv/), which also provides the Python 3.12 it needs:

```sh
uv tool install --python 3.12 pyocd
```

### Linux: access to the Connect Kit

On Linux, only root can use the Connect Kit's debug probe and serial ports until you allow otherwise. Add a udev rule for the probe, and add yourself to the group that owns serial ports:

```sh
printf '%s\n' \
  'SUBSYSTEM=="usb", ATTR{idVendor}=="2fe3", ATTR{idProduct}=="0204", MODE="0660", GROUP="plugdev", TAG+="uaccess"' \
  'KERNEL=="hidraw*", ATTRS{idVendor}=="2fe3", ATTRS{idProduct}=="0204", MODE="0660", GROUP="plugdev", TAG+="uaccess"' \
  | sudo tee /etc/udev/rules.d/50-connectkit.rules
sudo udevadm control --reload-rules && sudo udevadm trigger
sudo usermod -aG dialout,plugdev "$USER"
```

Log out and back in for the group change to take effect.

## Get the source

```sh
git clone --depth 1 https://github.com/m4rkw/l0destar.git
cd l0destar/firmware
```

The remaining commands in this section run in `firmware/`. There is nothing more to set up by hand: the first build fetches the Connect Kit's board definition from Makerdiary and creates your firmware signing key.

!!! warning "No spaces in the path"
    Zephyr's build system breaks on source paths containing spaces. Clone into a path without them.

## Check the computer sees the board

Connect the Connect Kit with the USB-C cable, then:

```sh
pyocd list
```

It should list the probe as `Makerdiary IFMCU CMSIS-DAP`, with the target `nrf91`. The Connect Kit also has two serial ports, the first of which is the firmware console: `/dev/cu.usbmodem*` on macOS, and on Linux `/dev/serial/by-id/usb-Makerdiary_IFMCU_CMSIS-DAP_<serial>-if00`.

!!! tip "Working in a virtual machine"
    Flashing resets the Connect Kit's USB interface, so it disconnects and reconnects. Set the virtual machine to connect the device automatically, or it can end up back on the host after the first flash.

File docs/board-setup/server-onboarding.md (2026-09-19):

# Onboarding devices into the server

Your server only accepts telemetry from devices it knows. Enrolling a device records its IMEI and the key its firmware was built with, and from then on the server accepts what the device sends and answers it.

The server's tools run inside its container: `sudo docker exec l0destar python tools/<tool>.py`.

## Enrol the device

On the server, give `adddevice.py` the IMEI from the console on [minimal config and initial flashing](initial-flashing.md), a name, optionally the vehicle's registration, and the key from `CONFIG_APP_PSK_HEX` in your `local.conf`:

```sh
sudo docker exec l0destar python tools/adddevice.py 350000000000000 "Car" AB12CDE --psk <64 hex characters>
```

```text
enrolled Car (350000000000000)
```

- The **name** appears in every alert (`Car: movement: ...`) and in the device list. The **registration** is optional; when set, the map page shows it instead of the name.
- The IMEI must be 14 to 16 digits, and a device cannot be enrolled twice.
- Keep the key in your password manager as well as in `local.conf`. No tool shows it again.

Nothing needs building or flashing again: the server accepts the device's next datagram. To have it send one now rather than at its next wake, restart it:

```sh
# on the build machine, in firmware/
./reset.sh
```

Reopen the console, which the reset disconnects. Once the modem has registered, the device sends, and this time the server answers. The console shows the reply, and with pin 5 off the device then goes back to sleep:

```text
<inf> main: imei=350000000000000
<inf> transport: sent 332 bytes
<inf> data: resp: 1,0,1,track=0
<inf> main: entering sleep
```

On the server, `udp.log` records the device, and the device list shows when it was last heard from:

```sh
# on the server
tail -n 3 /srv/l0destar/logs/udp.log
sudo docker exec l0destar python tools/device.py list
```

```text
2026-09-13 17:51:56 2 records from 350000000000000 (203.0.113.7)

imei             name        registration  last seen            firmware  battery  ignition
350000000000000  Car         AB12CDE       2026-09-13 17:51:56  0.4.0     12.01V   off
```

The address in `udp.log` is your mobile operator's, not the SIM's own.

[Verifying telemetry](verifying-telemetry.md) goes through the rest of the checks.

!!! note "Letting the server choose the key"
    Without `--psk`, `adddevice.py` generates a key and prints it once. That suits a device whose firmware does not have a key yet: put the printed key in `CONFIG_APP_PSK_HEX`, then build and flash again.

## What a new device starts with

| Setting | Default | Meaning |
|---|---|---|
| `int` | `0` | Engine-off timed wake interval, in seconds. `0` means no timed wakes: the device still wakes on ignition, movement, knocks and tilt. |
| `ma` | `1` | The movement alarm flag. Firmware 0.4.x reports it but does not act on it: movement, impact and tilt alerts are raised either way. |
| `track_mode` | `0` | Track mode, switched on per session from the web page. |
| `alarm` | `0` | Server alert whenever the ignition comes on. |
| `garage` | `0` | Marks a vehicle expected to be moved, downgrading urgent alerts. |
| `overnight_alarm` | `0` | Server alert when the ignition comes on overnight (23:00 to 06:00 unless changed). |

`int`, `ma` and `track_mode` travel to the device in every reply; the other three only change what the server does. To change them use `command.py` or the API - every setting and command is in [device settings and commands](../reference/device-settings.md), and what `int` costs in battery is worked out in [deployment configuration](../deployment/configuration.md). For example, to have a parked vehicle report every hour:

```sh
sudo docker exec l0destar python tools/command.py 350000000000000 int=3600
```

`command.py` uses the API token created during [server installation](../server/installation.md). A setting like `int=` waits in the queue until the device next reads a reply; server-only settings such as `alarm=1` take effect immediately.

## More than one device

Enrol each device the same way. Every device has its own IMEI, its own key and its own section in `remote.conf` with its own board and interface settings; nothing is shared between them.

- Give each a name you will recognise in an alert.
- The web interface lists them all on its device page and opens the map for whichever you choose; see [web interface and API](web-interface.md).
- API calls that only read can fall back to a default device, but calls that change anything - settings, commands, track mode - must name the device.

## Managing devices

`tools/device.py` looks after enrolled devices:

| Command | What it does |
|---|---|
| `list` | Lists every enrolled device. |
| `show <imei>` | One device's settings, update state, most recent record and queued commands. |
| `rename <imei> <name> [registration]` | Changes the name, and the registration if given. |
| `rekey <imei> [--psk <64 hex>]` | Replaces the device's key, printing the new key once. |
| `remove <imei> --yes` | Deletes the device and all of its history. |

```sh
sudo docker exec l0destar python tools/device.py list
sudo docker exec l0destar python tools/device.py show 350000000000000
sudo docker exec l0destar python tools/device.py rename 350000000000000 "Van" XY34FGH
```

!!! danger "remove deletes the history"
    `remove` deletes the device's telemetry, journeys, fault codes and queued commands along with the device. There is no undo, so back up the database first. When you retire a device, also delete its section from `remote.conf` and its `manifest-<imei>.txt` and images from the server's firmware directory.

## Changing a device's key

### On the bench

1. Generate a new key with `openssl rand -hex 32`, put it in `local.conf`, then build and flash.
2. Give the server the same key:

```sh
sudo docker exec l0destar python tools/device.py rekey 350000000000000 --psk <64 hex characters>
```

Until both have the new key, the server rejects what the device sends.

### A device in the field

Order matters here: the device can only learn about new firmware from replies it can still decrypt.

1. On your build machine, generate the new key:

```sh
openssl rand -hex 32
```

2. Put it in the device's section of `remote.conf` and publish:

```sh
# in firmware/
./push_fw.sh --device 350000000000000
```

The device still uses its old key, so it sees the update in its replies and installs it as normal.

3. When the new image starts, it uses the new key and the server rejects its records. Its update check at start-up still reaches the server over TLS, which confirms the update and sends `Car: fota: updated to <version>`. That is your signal. If it has not arrived within about 15 minutes of the download finishing, look at the server's logs instead: `decrypt failed` lines in `udp.log` from the address the device reports from mean it is already sending with the new key, and a `/fw/manifest.txt` request in `tls.log` after the download's last range means it has restarted.
4. Straight away, give the server the same key:

```sh
sudo docker exec l0destar python tools/device.py rekey 350000000000000 --psk <64 hex characters>
```

Records sent between steps 3 and 4 are lost. This is also how to retire a key you think has leaked, for example with a firmware image; see [server security](../server/security.md).

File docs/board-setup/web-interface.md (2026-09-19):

# Web interface and API

The server's web interface shows every enrolled vehicle, its live position, its journeys, and the engine and motion data it reports. The same server offers a small HTTP API for scripts and home automation.

Examples use `https://tracker.example.com`; use whatever hostname you serve the interface on (see [server security](../server/security.md) for serving it privately over Tailscale).

## Signing in

The server uses passkeys only - there are no passwords.

1. On the server, create a sign-up link for the person:

```sh
sudo docker exec l0destar python tools/regtoken.py alice tracker.example.com
```

It prints a link like `https://tracker.example.com/register?username=alice&token=...`, valid once, for 24 hours. Creating another link for the same username cancels this one.

2. Open the link **on the device that will hold the passkey** and press **register**. Registration asks for the device's own authenticator, with user verification - iCloud Keychain, Google Password Manager, Windows Hello and the like - so browsers do not offer roaming security keys.
3. When it says `passkey registered successfully`, follow **continue to login**, enter the username and approve the passkey prompt.

Things to know:

- **Hostname.** A passkey belongs to the hostname it was created on. Always open the interface on the same hostname that was in the sign-up link: a Tailscale name and a public name are different sites as far as passkeys are concerned.
- **Lost phone.** Create a new link for the same username. Registering replaces the old passkey and signs the lost phone out.
- **Sessions** last 30 days (`session_lifetime_days`). **logout** ends one.
- **Lockouts.** Five failed passkey verifications lock the account. Separately, after five sign-in attempts from one address without a successful login, further attempts get `too many requests` until an hour after the last one. [Server security](../server/security.md) covers unlocking an account.

## Choosing a vehicle

Signing in lands on the map for your default vehicle - `default_device` in the server's configuration, or the only enrolled device if there is just one. Otherwise it lands on the device list at `/devices`.

The device list shows every enrolled device by name, with its registration, IMEI, when it was last heard from, ignition or engine state, battery voltage, speed, firmware version and network. Choose one to open its map at `/track?imei=<imei>`. With no devices enrolled it says so and points at `tools/adddevice.py`.

## The map page

The top of the page shows:

- The vehicle's **registration**, or its name if it has none.
- Links: **gps** opens the last position in Google Maps; **history**, **track** and **logout**; and **devices**, back to the device list, when more than one device is enrolled.
- The mobile **operator** and radio technology (`CATM1` for LTE-M), and the **battery voltage**. The voltage turns red when the vehicle is moving with the ignition on but no charging is detected - worth checking the alternator.
- The **date and time** the latest record reached the server.
- **Speed** in mph: the ECU's own figure when the device reports one, GNSS otherwise.
- **State**: `engine on`, `ignition on` or `ignition off`. The engine counts as running when the ECU reports RPM above zero, or, without ECU data, when any of the last `engine_stopped_count` (10) battery readings was at or above `engine_running_voltage` (13.0V) - a charging alternator holds the voltage up, and the window stops smart charging systems flickering the display.

The page follows the vehicle live over a WebSocket and reconnects by itself if the connection drops. It needs a Google Maps key (`google_maps_api_key`); without one, a note takes the place of the map and everything else still works.

### ECU panel

Shown only when records carry OBD-II data, which means a K-wire build with OBD telemetry enabled ([deployment configuration](../deployment/configuration.md)). It shows RPM, coolant and intake temperature, engine load, throttle, mass air flow, timing advance, short and long-term fuel trims and fuel system status. Coolant at 110°C or more, fuel trims beyond ±10% and a fault in the fuel system status are highlighted, and a line appears when the check engine light is on, with the number of stored fault codes. A value the ECU did not report in that record shows as a dash.

### IMU panel

Built from the accelerometer and gyroscope. Because the tracker can be mounted in any orientation, everything is measured against gravity as the device sees it while stationary:

- **g force** - horizontal acceleration from braking, accelerating and cornering, coloured by whether the vehicle is speeding up or slowing down.
- **bump** - vertical acceleration, from potholes and speed humps.
- **yaw** - turning rate in degrees per second.
- **tilt** - the angle away from the resting position, shown only while stationary, where it means jacking or towing.
- **imu temp** - the sensor's temperature.

### History and replay

**history** lists completed journeys, newest first, with their start time and distance; **Load more** fetches older ones. Place names show as `?` because nothing in the server fills them in.

Choose a journey to replay it: the route is drawn on the map and the vehicle moves along it, with the panels showing what was recorded at each point. The controls stop the replay and return to the live view, skip back or forward ten points, pause, and scrub with the slider.

### Track mode

Track mode is for track days and bench runs. **track** asks for confirmation and then switches it on for that vehicle: the tracker stops GNSS, polls the ECU continuously and sends a record about once a second with a burst of motion samples, and the map is replaced by a dashboard - RPM with a redline bar, speed, throttle and load, a friction circle and a 60 second trace of RPM, throttle and g, and tiles for the slower values, battery, data rate and the age of the latest record.

- The device picks up the switch the next time it reads a reply - within about 30 seconds with the ignition on - and the dashboard shows "waiting for the device to enter track mode" until then.
- It only works with the ignition on, and most of the dashboard needs a K-wire build with OBD telemetry.
- It ends by itself when the ignition goes off. If the device lost power or coverage before it could report that, the server clears the switch when it next hears from the device after more than an hour of silence. Either way, switch it on again for each session.
- The dashboard learns which way is forward from the first firm braking or acceleration (it shows "orienting… brake or accelerate" until then) and remembers it in your browser for that vehicle.

!!! danger "Drive safely"
    Track mode is for closed circuits, private land and the bench. On a public road obey the law and keep your eyes on the road, not on the dashboard - its figures are for looking at afterwards. You alone are responsible for how you drive.

## HTTP API

All responses are JSON with `"status": "ok"`, or `"status": "error"` and a `"message"`.

### Which device a request is about

- Requests that only read data use the device named by `imei` or `device_id` (in the query string or the JSON body), or by the `X-Imei` header. When they name none they use `default_device`, then the only enrolled device.
- Requests that change something - `POST /api/1.0/config`, `POST /api/1.0/command` and `POST /api/1.0/trackmode` - must name the device with `imei`, `device_id` or `X-Imei`, and fail with `imei or device_id required` otherwise.
- A request that names a device that is not enrolled fails with `device not found`. It never falls back to another vehicle.

### Browser endpoints

These use the signed-in session, and are what the web page itself calls. Without a session they redirect to the sign-in page.

| Endpoint | Returns |
|---|---|
| `GET /api/1.0/devices` | Every device: `id`, `imei`, `name`, `registration`, `last_seen`, `latitude`, `longitude`, `speed`, `battery_level`, `ignition_state`, `fw`, `rat`, `operator`, `track_mode`. |
| `GET /api/1.0/carpos` | The latest `position`, the resting accelerometer reading (`accel_baseline`) and the `track_mode` switch. |
| `GET /api/1.0/status` | The device's IMEI, name, synced settings (`int`, `ma`), firmware version and last-seen time. |
| `GET /api/1.0/journeys` | Completed journeys, newest first: `page` (from 0) and `per_page` (default 50, at most 200). |
| `GET /api/1.0/journey/<id>/points` | Every point of one journey. With `imei`, an error if the journey belongs to another device. |
| `GET /api/1.0/trackmode`, `POST /api/1.0/trackmode` | Read, or set with `{"imei": "...", "on": 1}`, the track mode switch. |
| `GET /ws/carpos?imei=<imei>` | The live WebSocket stream (below). |

### Automation endpoints

These take a bearer token instead of a session. Create one per consumer on the server:

```sh
sudo docker exec l0destar python tools/gentoken.py home-automation
```

A token is not limited to particular devices or actions: anything holding one can change settings and queue commands such as `reboot`. Treat it like shell access, and see [server security](../server/security.md) for revoking one.

| Endpoint | What it does |
|---|---|
| `GET /api/1.0/track` | Redirects to a map at the device's last position: an Apple Maps link by default, Google Maps with `google=1`. With `return=1` it returns `{"url": ...}` instead of redirecting. |
| `GET /api/1.0/config` | The device's settings: `int`, `ma`, `al` (alarm), `ga` (garage), `oa` (overnight alarm), `oaf` and `oat` (overnight window hours). |
| `POST /api/1.0/config` | Sets any of those fields. Values must be whole numbers: 0 or 1 for the switches, 0-23 for the hours. |
| `POST /api/1.0/command` | Queues a command for the device, or applies a server-side setting. |
| `POST /api/1.0/home` | The home check (below). |

```sh
TOKEN=<token from gentoken.py>

# read a device's settings
curl -s -H "Authorization: Bearer $TOKEN" \
  "https://tracker.example.com/api/1.0/config?imei=350000000000000"

# report every hour while parked
curl -s -X POST -H "Authorization: Bearer $TOKEN" -H "Content-Type: application/json" \
  -d '{"imei": "350000000000000", "int": 3600}' \
  https://tracker.example.com/api/1.0/config

# ask for the current position as an alert
curl -s -X POST -H "Authorization: Bearer $TOKEN" -H "Content-Type: application/json" \
  -d '{"imei": "350000000000000", "command": "locatenow"}' \
  https://tracker.example.com/api/1.0/command

# a Google Maps link to the last position
curl -s -H "Authorization: Bearer $TOKEN" \
  "https://tracker.example.com/api/1.0/track?imei=350000000000000&google=1&return=1"
```

### Commands

A command waits on the server until the device next reads a reply, and is handed over once: if that reply is lost, queue it again. Queuing a command replaces a pending one it supersedes (`locate` and `locatenow`, for instance), and several can be sent at once separated by commas. Server-side settings in the same request - `alarm=`, `garage=`, `overnightalarm=` and the overnight hours - take effect immediately and never go to the device. The full list is in [device settings and commands](../reference/device-settings.md#commands); from the server's shell, `tools/command.py` does the same job:

```sh
sudo docker exec l0destar python tools/command.py 350000000000000 locate
```

### Live stream

`/ws/carpos?imei=<imei>` is the WebSocket the map page uses. It needs a signed-in session, so it is for browsers rather than scripts. On connecting it sends the latest record, then every new record as it arrives, each as the `position` object that `carpos` returns - coordinates, speeds, heading, timestamp, battery, ignition, operator, the OBD and IMU readings, and in track mode the unpacked motion burst - but not `carpos`'s `accel_baseline`. When nothing new has arrived for 10 seconds it sends `{"ping": true, "track_mode": 0}`, carrying the track mode switch, so the connection is not dropped.

### Home check

A tracker that stops reporting while parked at home is hard to notice: its last record looks exactly like a car parked at home. The home check catches the opposite case - the last known position is not where the vehicle should be.

List each vehicle's home in `home_check` in the server's configuration (see [server configuration](../server/configuration.md)), then call the endpoint on a schedule from the server itself, at a time the vehicles should be home - [server deployment](../server/deployment.md#scheduling-the-home-check) has the details:

```text
# /etc/cron.d/l0destar-home-check: every night at 03:00
0 3 * * * nobody curl -fsS -X POST -H "Authorization: Bearer <token>" http://127.0.0.1:5000/api/1.0/home > /dev/null
```

It checks every configured vehicle, or only the one `?imei=` names (an IMEI with no `home_check` entry fails with `no home_check entry for <imei>`), and returns a `devices` list with each vehicle's `imei`, `name`, `at_home`, `distance_m` and `garage` flag. A vehicle that cannot be checked carries an `error` instead - `device not found` or `no position recorded`. A vehicle away from home that is not in garage mode raises `<name>: tracker may be stalled - vehicle is <n>m from home`.

## Google Maps key

The map uses the Google Maps JavaScript API. Create a key in the Google Cloud console with that API enabled, restrict it to your interface's address with an HTTP referrer restriction - the key is sent to every browser that loads the page and cannot be kept secret - and set it as `google_maps_api_key` in `config.yaml`. The [server configuration](../server/configuration.md) page covers the setting.

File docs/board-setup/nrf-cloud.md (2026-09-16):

# nRF Cloud onboarding

nRF Cloud is free for up to 10 devices and allows the use of A-GNSS (Assisted
GPS) which lets the tracker get GPS fixes much faster than it otherwise would.

## Initial setup

1. Register for nRFCloud and get your API key from this page: https://app.nrfcloud.com/#/account

Note: you may be redirected to memfault.com, this is Nordic's new interface. For
reasons I don't yet understand the new interface gives a different API key that
doesn't work with this onboarding process (open ticket:
https://devzone.nordicsemi.com/support/362337). If you get redirected go back
to https://app.nrfcloud.com, click the lines in the top right of the page, then
User Account. On this page your API key will be available.

```
export NRF_CLOUD_API_KEY=<your API key>
```

2. Install the nrfcloud-utils

```
uv tool install --python 3.12 nrfcloud-utils
```

3. Create a CA for your devices

This should only be done once, the CA is used for all of your devices. Replace
'GB' with your country code. This CA is only used to vouch for your devices to
nRFCloud, it is completely separate from any CAs that might be configured on
your instance of the server component.

```
git clone https://github.com/m4rkw/l0destar
cd firmware
mkdir -p onboarding
create_ca_cert -c GB -o l0destar -p onboarding -f l0destar
```

4. Build and flash the provisioning firmware

```sh
# in firmware/
PROV=1 BUILD_SUBDIR=build_prov ./build.sh
pyocd load -t nrf91 --no-reset build_prov/merged.hex
pyocd reset -t nrf91 -m hw -O auto_unlock=false
```

5. Install the device credentials

```sh
# in firmware/
device_credentials_installer \
  --port /dev/cu.usbmodem*1 --cmd-type at \
  --ca onboarding/*_ca.pem \
  --ca-key onboarding/*_prv.pem \
  --id-imei --id-str nrf- \
  -S 16842753 -d \
  --csv onboarding/onboard.csv --verify
```

The modem generates a private key that never leaves it, the tool signs a certificate for it with your CA and writes the certificate back into the modem, and a row describing the device is written to `onboarding/onboard.csv`.

- `--id-imei --id-str nrf-` names the device `nrf-<IMEI>`, and `-S 16842753` stores the credentials at the security tag the firmware uses. Both must be exactly as shown, or nRF Cloud rejects the firmware's requests.
- `-d` deletes anything already stored at that tag first, so running it again is safe.
- `onboard.csv` is overwritten on each run, so it only ever describes the device you just provisioned.

6. Onboard the device to your account

```sh
# in firmware/
nrf_cloud_onboard --api-key "$NRF_CLOUD_API_KEY" --csv onboarding/onboard.csv
```

Check that nRF Cloud now lists `nrf-<IMEI>`:

```sh
curl -s "https://api.nrfcloud.com/v1/devices" -H "Authorization: Bearer $NRF_CLOUD_API_KEY"
```

For each further device, repeat steps 2 to 4 with the same CA.

7. Back to the tracker firmware

The provisioning firmware does not track anything. Flash the tracker firmware back: the provisioning build went into its own directory, so `build/` still holds it.

```sh
# in firmware/
./flash.sh
```

From then on, when the tracker registers on the network at start-up, it fetches assistance data before starting GNSS:

```text
<inf> agnss: requesting A-GNSS data from nRF Cloud...
<inf> agnss: received <n> bytes, processing
<inf> agnss: A-GNSS data injected
```

| Message | Meaning |
|---|---|
| `JWT needs modem time; waiting for NTP fallback...` | Normal just after start-up, until the network has provided the time. |
| `agnss_data_get: ... (HTTP 401)` | nRF Cloud refused the device's token ("Auth token is malformed"): the device is not onboarded to your account, or its ID or security tag differs from the commands above. |
| `no network yet — skipping A-GNSS, GNSS will ask later` | The modem had not registered in time; the firmware requests assistance again once GNSS needs it. |

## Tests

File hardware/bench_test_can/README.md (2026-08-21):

# l0destar v1.0 bench test unit - CAN version

## Overview

NOTE: THIS HAS NOT BEEN TESTED, USE AT YOUR OWN RISK

This is a bench test PCB designed for use with the Nordic nRF9151 Dev Kit. It
has all of the ancillary electronics with pin headers intended for connection to
the dev kit:

 - ~12v power input
 - 3.3V buck powering a 3V relay which gates the 12V supply to the rest of the
   board
 - All power rails (including 12v) gated by the presence of the 3.3v rail from
   the dev kit using a 3V relay (see below)
 - INA228 voltage monitoring
 - Manual switch to simulate the ignition signal
 - Relay power source switching
 - 5V buck converter for the ISO-9141
 - Auxillary power rails controlled by the AUX_SW signal
 - Accelerometer (pin headers to accept the STEVAL-MKI212V1 accelerometer eval
   board
 - MikroBUS headers wired for the MIKROE-2379 CAN-FD ClickBoard

## Disclaimer

This is a prototype, not a product. Nothing here is validated or certified,
the parts lists are examples rather than a verified BOM, and any test results
recorded below are my own unverified bench observations - repeat the testing
yourself rather than taking them on trust.

**Before building or installing anything from this repository, read the
[full disclaimer](../../DISCLAIMER.md).**

## Power supply

The 12V input goes via an initial relay stage which gates power to the rest of
the board. The 3.3V rail from the DK must be present in order for everything on
the test board to power on. This is because having voltage on any of the GPIO
signal lines while the DK is powered off is not recomended by Nordic. This
configuration means that as soon as the 3.3V rail from the Nordic board goes off
the power is cut to the entire accessory board.

WARNING: logic voltage on the MIKROE-2379 should be set to 3.3v as 5v would
damage the nRF9151.

## Parts list

| Part | Quantity |
|---|---|
| [3V relay](https://amzn.to/43xMQR2) | 1 |
| [3.3v buck converter](https://amzn.to/4fIUC1W) | 1 |
| [RT424F12 12V bistable relay](https://amzn.to/4egbXN5) | 1 |
| [STEVAL-MKI212V1 accelerometer eval board](https://www.st.com/en/evaluation-tools/steval-mki212v1.html) | 1 |
| [MIKROE-2379](https://amzn.to/4emx1BS) | 1 |
| [INA228 breakout](https://amzn.to/4efyaed) | 1 |
| [5V buck converter](https://amzn.to/4uwe5Gy) | 1 |
| [5mm switch](https://amzn.to/3S40cCg) | 1 |
| [Pin headers](https://amzn.to/3Qm8qoH) | Various  |
| [4.7K resistor](https://amzn.to/4gc8ZvK) | 2 |
| [10K resistor](https://amzn.to/4gc8ZvK) | 9 |
| [56K resistor](https://amzn.to/4gc8ZvK) | 2 |
| [100K resistor](https://amzn.to/4gc8ZvK) | 7 |
| [MOSFET - ZVN4206A](https://amzn.to/3S775mb) | 4 |
| [MOSFET - DMG3415U](https://amzn.to/4uvGYCY) | 2 |
| [SOT-23 adapter](https://amzn.to/4fIxoc5) | 2 |
| [100nF ceramic capacitor](https://amzn.to/4xpB60v) | 1 |
| [Diode - 1N4148](https://amzn.to/4vPo4bi) | 2 |
| [Molex 43045-0400 4-pin receptacle](https://uk.farnell.com/molex/43045-0400/conn-r-a-hdr-4pos-2row-3mm/dp/9733019) | 1 |

## Tools and accessories

- [Dupont connectors and pins](https://amzn.to/444K71B)
- [Crimp tool for Dupont terminals](https://amzn.to/4xraxZ0)
- [Ribbon cable](https://amzn.to/3PXOW9R)
- [Klein 2100-5 scissors](https://amzn.to/4vEJpnA)
- [PCB header pins](https://amzn.to/43xhjPk)

## Notes

- I mounted the DMG3415Us on SOT-23 adapters but there's no reason you need to
  if you'd rather surface mount them
- The breakouts can either be soldered directly or mounted on PCB pin headers, I
  would suggest the latter for ease of re-use
- Any buck converters with stable output will work. The 3.3V one is necessary
  to drive the relay coils because they draw over 100mA and I wasn't comfortable
  putting that load on the Nordic VDDIO rail comfortable putting that load on
  the Nordic VDDIO rail. I positioned the 2pin connector footprints for the
  modules I bought, if you buy different ones you'll need to adjust them
- I used a 4-pin Molex receptable because it's what I had to hand but only two
  of the pins are needed
- Never plug or unplug anything into the Nordic dev board while anything is
  powered (I killed at least one dev board this way)
- This PCB has not been tested or validated at all yet, I would strongly
  recommend carefully testing it (ideally with an oscilloscope) before
  connecting it to the dev board

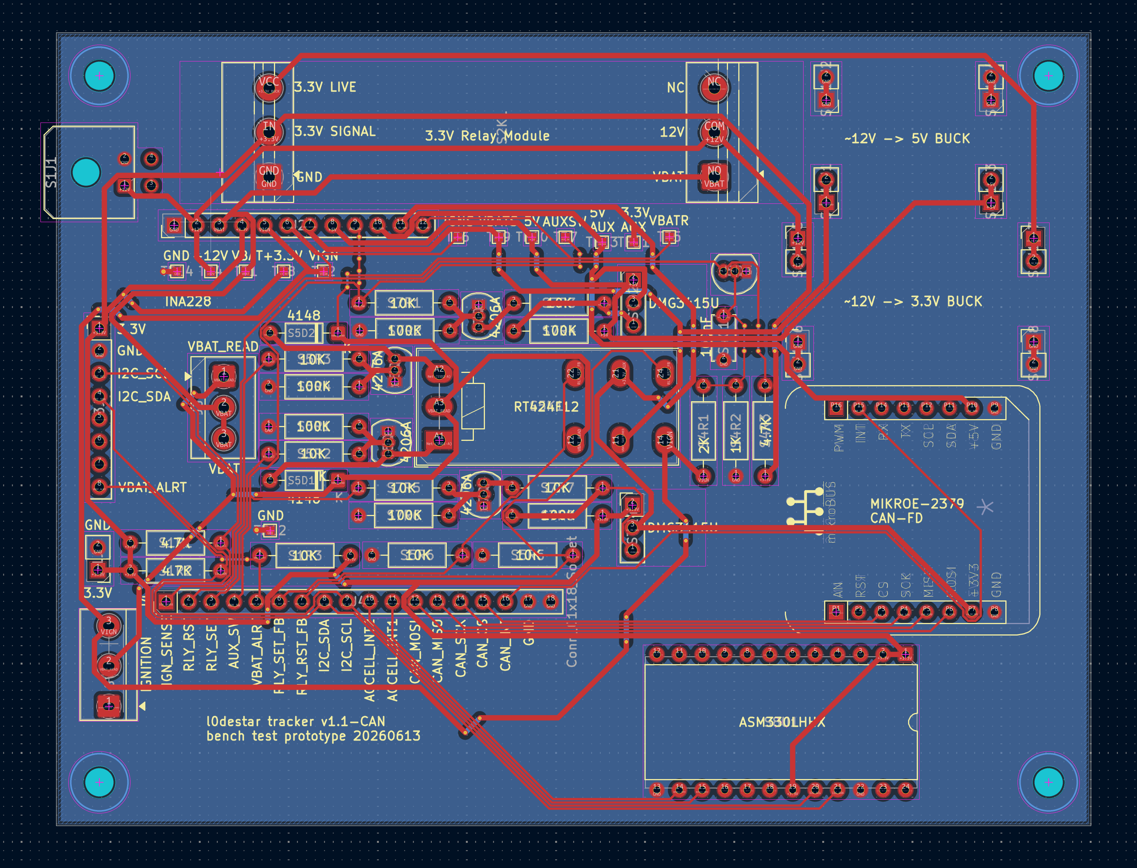
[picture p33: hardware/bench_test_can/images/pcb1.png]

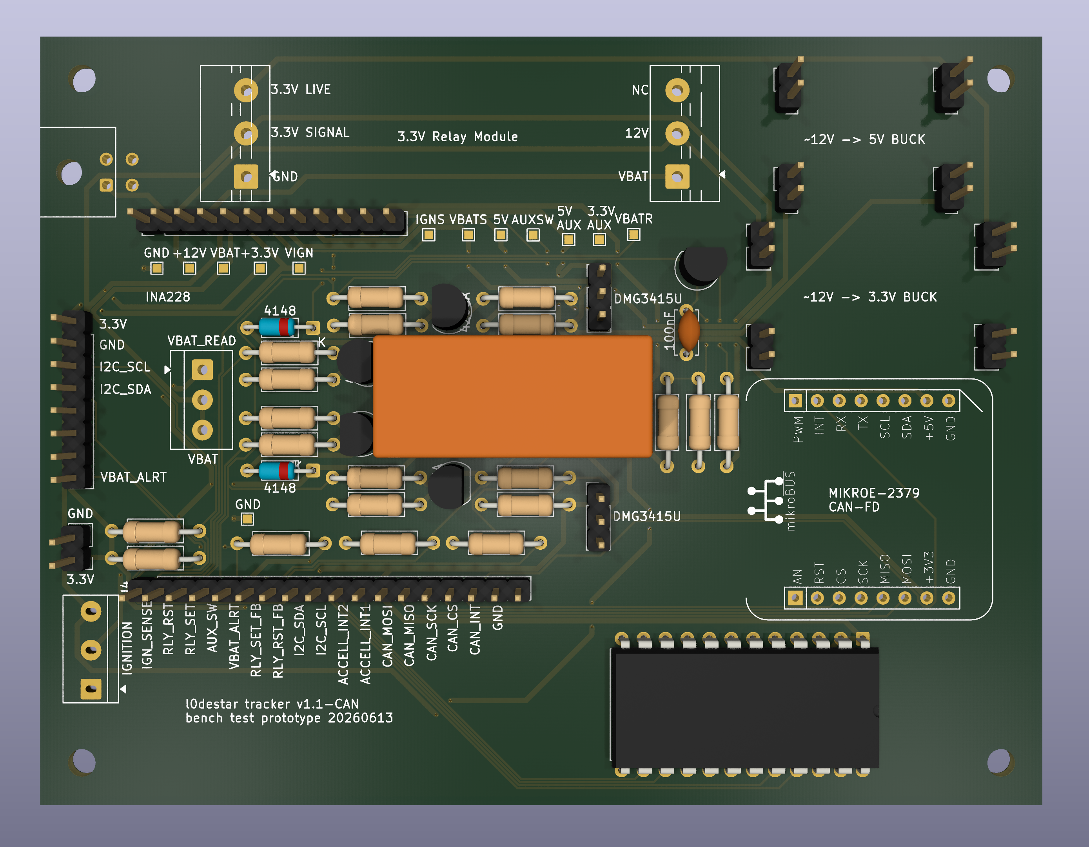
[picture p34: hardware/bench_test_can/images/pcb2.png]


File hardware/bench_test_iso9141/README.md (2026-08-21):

# l0destar v1.0 bench test unit - ISO-9141 version

## Overview

NOTE: THIS HAS NOT BEEN TESTED, USE AT YOUR OWN RISK

This is a bench test PCB designed for use with the Nordic nRF9151 Dev Kit. It
has all of the ancillary electronics with pin headers intended for connection to
the dev kit:

 - ~12v power input
 - 3.3V buck powering a 3V relay which gates the 12V supply to the rest of the
   board
 - All power rails (including 12v) gated by the presence of the 3.3v rail from
   the dev kit using a 3V relay (see below)
 - INA228 voltage monitoring
 - Manual switch to simulate the ignition signal
 - Relay power source switching
 - 5V buck converter for the ISO-9141
 - Auxillary power rails controlled by the AUX_SW signal
 - Accelerometer (pin headers to accept the STEVAL-MKI212V1 accelerometer eval
   board
 - Dual L9637D chips on DIP adapters to simulate K-line communications

## Disclaimer

This is a prototype, not a product. Nothing here is validated or certified,
the parts lists are examples rather than a verified BOM, and any test results
recorded below are my own unverified bench observations - repeat the testing
yourself rather than taking them on trust.

**Before building or installing anything from this repository, read the
[full disclaimer](../../DISCLAIMER.md).**

## Power supply

The 12V input goes via an initial relay stage which gates power to the rest of
the board. The 3.3V rail from the DK must be present in order for everything on
the test board to power on. This is because having voltage on any of the GPIO
signal lines while the DK is powered off is not recomended by Nordic. This
configuration means that as soon as the 3.3V rail from the Nordic board goes off
the power is cut to the entire accessory board. On my oscilloscope and with the
specific level shifters I got from amazon (not linked below as they're no longer
available) repeated tests of the falling edge showed no spikes at all and the
lines on the LV side of the shifter were always below the 3.3V reference rail.
However I would strongly encourage anyone considering using this board to do
their own testing with the specific parts they end up using. The Nordic board
GPIOs are only specced for ~0.3v over their VDDIO voltage, if the board is
unpowered that VDDIO is 0v.

## Parts list

| Part | Quantity |
|---|---|
| [3V relay](https://amzn.to/43xMQR2) | 1 |
| [3.3v buck converter](https://amzn.to/4fIUC1W) | 1 |
| [RT424F12 12V bistable relay](https://amzn.to/4egbXN5) | 1 |
| [STEVAL-MKI212V1 accelerometer eval board](https://www.st.com/en/evaluation-tools/steval-mki212v1.html) | 1 |
| [L9637D](https://amzn.to/3QFI7Ka) | 2 |
| [INA228 breakout](https://amzn.to/4efyaed) | 1 |
| [5V buck converter](https://amzn.to/4uwe5Gy) | 1 |
| [5mm switch](https://amzn.to/3S40cCg) | 1 |
| [Level shifter](https://amzn.to/4apB7I4) | 1 |
| [Pin headers](https://amzn.to/3Qm8qoH) | Various  |
| [510R resistor](https://amzn.to/4gc8ZvK) | 1 |
| [4.7K resistor](https://amzn.to/4gc8ZvK) | 2 |
| [10K resistor](https://amzn.to/4gc8ZvK) | 9 |
| [56K resistor](https://amzn.to/4gc8ZvK) | 2 |
| [100K resistor](https://amzn.to/4gc8ZvK) | 7 |
| [MOSFET - ZVN4206A](https://amzn.to/3S775mb) | 4 |
| [TVS Diode - P6KE24CA](https://amzn.to/4aLxvAd) | 1 |
| [MOSFET - DMG3415U](https://amzn.to/4uvGYCY) | 2 |
| [SOT-23 adapter](https://amzn.to/4fIxoc5) | 2 |
| [100nF ceramic capacitor](https://amzn.to/4xpB60v) | 5 |
| [10uF ceramic capacitor](https://amzn.to/4xpB60v) | 2 |
| [Diode - 1N4148](https://amzn.to/4vPo4bi) | 2 |
| [Molex 43045-0400 4-pin receptacle](https://uk.farnell.com/molex/43045-0400/conn-r-a-hdr-4pos-2row-3mm/dp/9733019) | 1 |

## Tools and accessories

- [Dupont connectors and pins](https://amzn.to/444K71B)
- [Crimp tool for Dupont terminals](https://amzn.to/4xraxZ0)
- [Ribbon cable](https://amzn.to/3PXOW9R)
- [Klein 2100-5 scissors](https://amzn.to/4vEJpnA)
- [PCB header pins](https://amzn.to/43xhjPk)

## Notes

- The TVS diode isn't strictly necessary on a bench
- I mounted the DMG3415Us on SOT-23 adapters but there's no reason you need to
  if you'd rather surface mount them
- The breakouts can either be soldered directly or mounted on PCB pin headers, I
  would suggest the latter for ease of re-use
- Any buck converters with stable output will work. The 3.3V one is necessary
  to drive the relay coils because they draw over 100mA and I wasn't comfortable
  putting that load on the Nordic VDDIO rail comfortable putting that load on
  the Nordic VDDIO rail. I positioned the 2pin connector footprints for the
  modules I bought, if you buy different ones you'll need to adjust them
- I used a 4-pin Molex receptable because it's what I had to hand but only two
  of the pins are needed
- Never plug or unplug anything into the Nordic dev board while anything is
  powered (I killed at least one dev board this way)
- This PCB has not been tested or validated at all yet, I would strongly
  recommend carefully testing it (ideally with an oscilloscope) before
  connecting it to the dev board

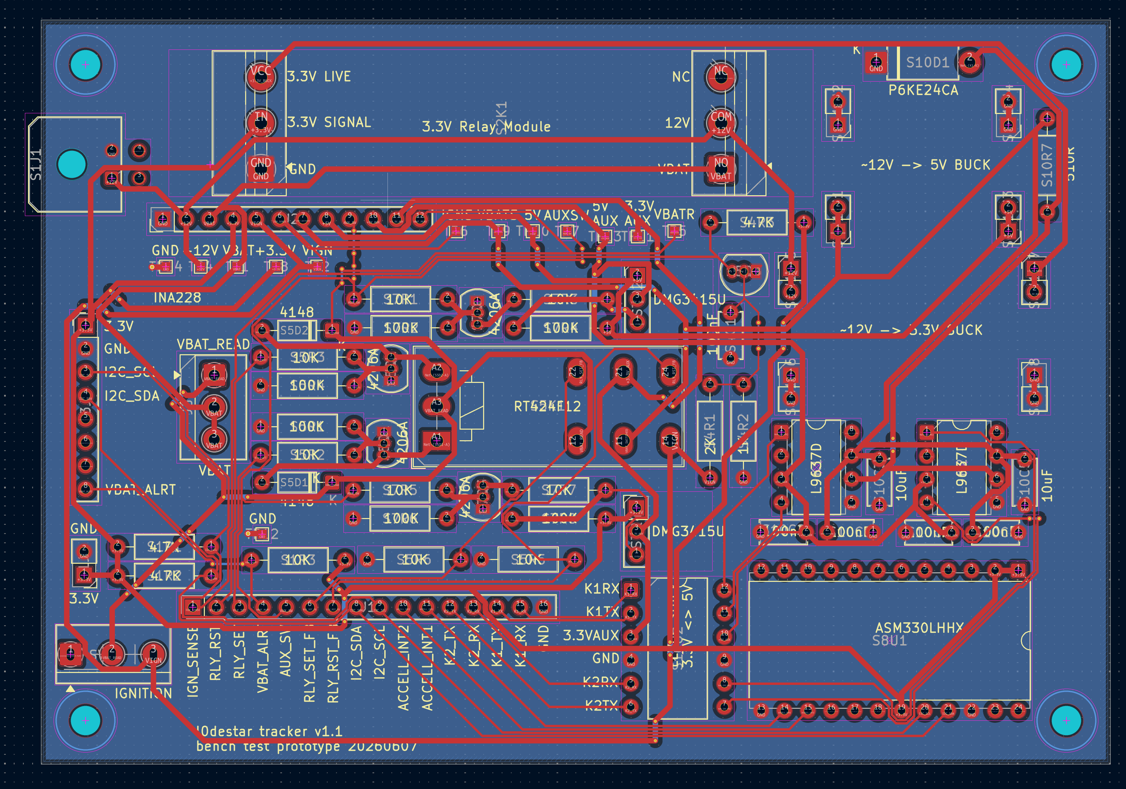
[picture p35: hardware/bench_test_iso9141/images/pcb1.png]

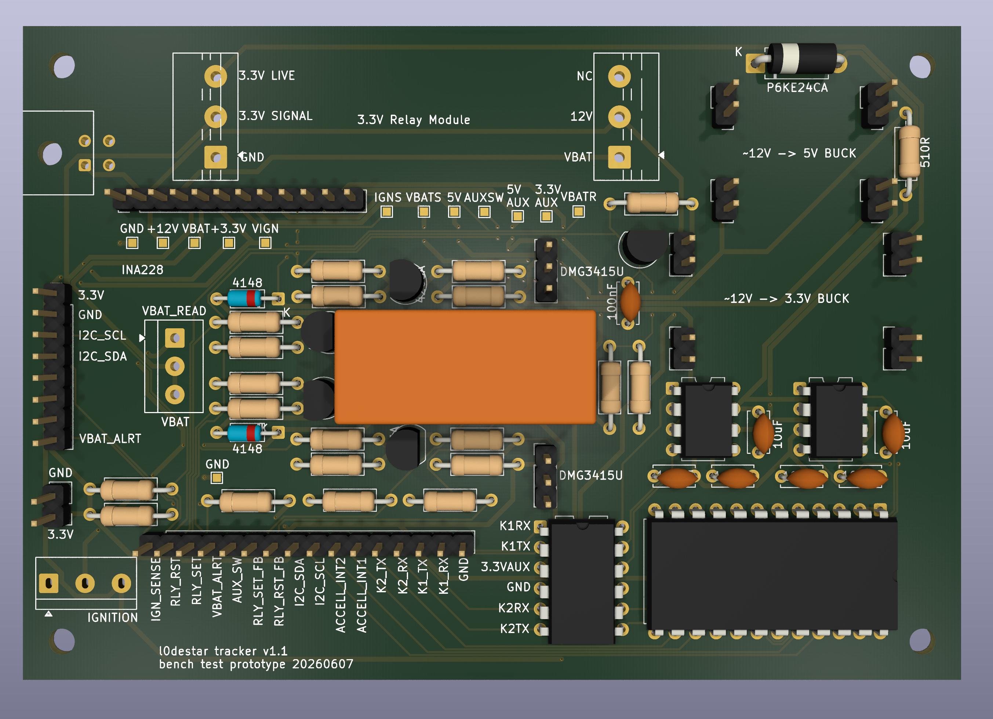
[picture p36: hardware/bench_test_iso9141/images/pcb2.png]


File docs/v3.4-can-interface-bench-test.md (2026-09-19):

# v3.4 CAN interface bench test

**The CAN interface on the v3.4 board, which replaces the MAX33041E transceiver with a TCAN3414DR, passes the same bench suite the v3.1 board did: about 60 000 frames in classic and FD modes, 125 kbps to 8 Mbps, with no corruption and no unprovoked errors up to and including 5 Mbps (two retried bit errors at 8 Mbps against the adapter, the same count as before; the board's own loopback at 8 Mbps is clean). On the oscilloscope the new part gives the same 2.0 V dominant differential with 30 ns edges in place of the MAX33041E's sub-10 ns ones, half the undershoot, and a loop delay of 86 / 107 ns, all inside its datasheet. Wake-on-bus through its wake-up-pattern standby works with the existing firmware.**

*MCP2518FD + TCAN3414DR · 19 September 2026 · [source, scripts and raw results in the firmware repository](https://github.com/m4rkw/l0destar) · the v3.1 board with the MAX33041E: [v3.1 CAN interface bench test](https://github.com/m4rkw/l0destar/blob/master/firmware/CAN_BENCH_REPORT.md)*

**This has not been tested in a vehicle yet (my car doesn't have CAN).**

## At a glance

| | |
|---|---|
| Hardware | No faults. Controller, crystal, transceiver, SPI wiring, CAN_INT, rail switching and wake-on-bus all behave as the datasheets say. Every PASS/FAIL row in the suite passed. |
| Bit-rate tolerance | −2.4 % to +2.6 %, symmetric around 500 kbps to within the ±0.3 % resolution of the test, identical to the v3.1 board: it is set by the crystals, not the transceiver. |
| Throughput, production SPI | 500 frames/s receive, 320 to 375 transmit; direct GPIO 2150 to 3340. The same as v3.1 within noise: the bit-banged SPI is the limit, not the bus. |
| 5 Mbps eye, worst bit of 495 | 1.96 V dominant differential at the sample point, against a 0.9 V threshold. Recessive 0 V ± 30 mV. Edges 27 ns, settled within 40 ns of a 200 ns bit. |
| Loop delay | TXD→RXD 86 ns recessive→dominant, 107 ns dominant→recessive; datasheet 95 / 120 ns typical, 180 ns max. |

## Setup

Two-node bus on the bench: the v3.4 board's TCAN3414DR at one end, a DSD TECH SH-C31A (CANable 2.0, STM32G431) at the other, 120 Ω at both ends, short cable, board powered over USB-C. The CAN circuit is otherwise the v3.1 design: MCP2518FD on a 40 MHz crystal, NUP2105L protector, 220 Ω series resistors on CAN_SDI/CAN_SCK and 1 kΩ on CAN_CS, the transceiver's STB pin driven by the controller's GPIO0 through XSTBYEN. The board runs a test agent (`src/can_bench.c`, `CONFIG_APP_CAN_BENCH=y`, board profile `APP_BOARD_L0DESTAR_V3_4`) that is driven from the host over the bus itself, so every command and reply is also a CAN exchange. Very short wires are soldered to the TCAN3414DR: CH1 CANH, CH2 CANL, CH3 TXD, CH4 RXD, with a common ground at the chip's GND pin.

- **Firmware agent** — owns the MCP2518FD. Counts and sequence-checks frames, echoes on ID+1, bursts, changes mode and timing, loopbacks, sleeps, cycles the rail, benchmarks the SPI link, reports TEC/REC and diagnostics.
- **Bit-banged SPI, two speeds** — production method (Zephyr GPIO API + 1 µs waits, ~130 kbit/s) or direct nrf_gpio with no waits (~890 kbit/s), switchable at run time.
- **Adapter** — the community gs_usb CAN FD fork (`tymmothy/candleLight_fw_canable_v2_fd` v1.0.1); the shipped candleLight build has no FD. Its quirks (128-byte padded USB frames, retry-forever jams, echo-on-queue, 160 MHz clock) are worked around in the host driver. Its own transceiver is a 5 V part: dominant CANH 3.5 V, CANL 1.4 V on the scope against the board's 3.0 / 1.0 V.
- **Host software** — pyusb gs_usb driver with FD and async USB, the adapter server on a local socket, and the test suite `can_bench/run_all.py`.

## Results

Run `can_bench/results/20260919-132751`. PASS and FAIL rows have a built-in criterion; INFO rows are measurements. "slow" is the production driver's SPI method, "fast" direct GPIO. The last column is the v3.1 board with the MAX33041E, from its own report, where the number differs or is worth setting side by side.

| id | test | result | key numbers | v3.1 / MAX33041E |
|---|---|---|---|---|
| A1 | Identification and idle state | PASS | Normal CAN 2.0, OSC 0x460, CAN_INT idle high, TEC/REC 0 | same |
| A2 | SPI link: MCP2518FD RAM sweep and transaction timing (slow/fast bit-bang) | PASS | 2 KB message RAM × 5 patterns (10 240 bytes) + 200 write/read/compare: 0 errors. 16-byte read (18 bytes on the wire) 1.10 ms slow (131 kbit/s), 0.16 ms fast (894 kbit/s) | 0 errors; 1.13 / 0.19 ms |
| A3 | CAN_INT line follows RX FIFO | PASS | CAN_INT low on all 30 frames while the FIFO held data, high otherwise | same |
| B1 | Classic 500 kbps frame integrity: DLC 0-8, std/ext IDs, data patterns (echo) | PASS | 53/53 frames echoed bit-exact: DLC 0–8, five patterns, 4 std + 4 ext IDs | same |
| B1r | Classic 500 kbps remote (RTR) frames received | PASS | 5/5 remote frames received and flagged | same |
| B2 | Classic 500 kbps round-trip latency (200 echoes, slow/fast SPI) | PASS | RTT 200 frames: slow 6.1 / 6.6 / 8.1 / 8.9 ms, fast 2.2 / 2.6 / 2.9 / 4.0 ms (min/med/p95/max) | slow 6.3 / 6.8 / 8.1 / 9.7, fast 2.5 / 3.0 / 3.3 / 5.0 |
| B3 | Classic 500 kbps host→device sustained rate limit | INFO | max lossless RX: slow 500 f/s (overflow from 551/s), fast 3340 f/s (overflow from 3755/s) | slow 500, fast 2500–3325 |
| B3b | Classic 500 kbps RX FIFO burst absorption | PASS | 16 and 32-frame bursts absorbed; 60 and 100 overflow with the flag raised (FIFO = 32) | same |
| B4 | Classic 500 kbps device→host bursts (500 frames, DLC 8/0, slow/fast SPI) | PASS | 500-frame bursts, all sequence numbers received: slow 318 (DLC 8) / 376 (DLC 0) f/s, fast 2153 / 2536 f/s | slow 350–440, fast 2000–3300 |
| B5 | Classic 500 kbps simultaneous bidirectional traffic (arbitration) | PASS | 200 host frames at 3 ms pace while device sent 200: 200/200 each way, no errors | same |
| B6 | Error counters clean after classic tests | PASS | TEC 0, REC 0, no flags, no diagnostics | same |
| C1 | Bit rates 125k / 250k / 500k / 1M | PASS | 125 k / 250 k / 500 k / 1 M: 20/20 echoes and 100/100 burst at each, TEC/REC 0 | same |
| C2 | Host sample-point sweep at 500 kbps | PASS | host sample point 60–95 %: 20/20 pings at every setting (board 80 %) | same |
| C3 | Host bit-rate offset tolerance at 500 kbps | INFO | lossless from −2.44 % to +2.56 %, fails at −3.03 % and +3.23 % (points ~0.6 % apart) | identical |
| D1 | CAN FD frame integrity 500k/2M: lengths 0-64, BRS, ext IDs (echo) | PASS | 36/36 FD frames echoed bit-exact, all DLC codes to 64 bytes, BRS, ext IDs | same |
| D2 | CAN FD data rates 1M / 2M / 4M / 5M / 8M (echo) | PASS | 20/20 64-byte BRS echoes at 1, 2, 4, 5 and 8 Mbps, TEC/REC 0; 0 data-phase errors to 5 M, 2 bit errors on own TX at 8 M, retried | same, including 2 bit errors at 8 M |
| D3 | CAN FD throughput both directions at 2M and 5M | PASS | 200/200 each way at 2 and 5 Mbps: dev→host slow 152 f/s, fast 1050 f/s | slow 156, fast 875 |
| D4 | CAN FD host→device sustained rate limit (64-byte frames) | INFO | max lossless RX, 64-byte frames: slow 500 f/s, fast 2914 f/s (bus limited) | 500 / 2951 |
| D5 | Classic-mode device facing FD frames (misconfiguration hazard) | INFO | classic-mode device vs 10 FD frames: received 0, REC 17, stuff-error diagnostic, 2000 error frames at the adapter | REC 25, otherwise same |
| D6 | Device FD loopback through the transceiver at 1M-8M (host stopped) | PASS | external loopback through the TCAN3414DR 16/16 at 1, 2, 4, 5, 8 Mbps, 0 mismatches, 0 errors | same, through the MAX33041E |
| D7 | FD 5M with TDC disabled | INFO | 5 Mbps with TDC off: 50/50, no data-phase errors (short bus) | same |
| E1 | No partner: one-shot abort, error-passive and recovery | PASS | one-shot: 11 single attempts, each an ACK error (11 × 8 = TEC 88); retry, no partner: TEC to the 128 error-passive ceiling; frame delivered when the partner returned, TEC 126 at the read; 15 after the next 100-frame burst | TEC 56 / 126 / 65 |
| E2 | Bus-off provocation and recovery | PASS | 400 same-ID frames from both ends, device 400/400 sent: no data-field collision produced, bus-off not reached, TEC/REC 0 | same |
| E3 | Listen-only mode is truly passive | PASS | listen-only: adapter saw no ACK; 4 frames counted only after the adapter went error-passive | 3 frames |
| E4 | Acceptance filter | PASS | filter 0x123: 20/20 matching, 40 rejected; accept-all restored 20/20 | same |
| E5 | RX FIFO overflow detection | PASS | 4-deep FIFO + 50-frame burst: 9 received, 6 overflow events flagged, recovered 20/20 | 9 received, 5 events |
| E6 | Sleep and wake-on-bus (transceiver standby vs awake) | INFO | Sleep + transceiver standby: WAKIF and CAN_INT low 3 ms after the host's first frame; transceiver awake: 20 ms (both timed from the host's USB send, which is where the spread comes from). Oscillator ready 366 µs after wake | 9 ms, 396 µs |
| E7 | CAN rail power cycle ×5 and re-init | PASS | 5 rail cycles: sense low 22 ms after off, controller back 24–25 ms after on, echo OK each time | 17–18 ms / 24–25 ms |
| E8 | Cold reboot re-init | PASS | cold reboot: agent back on the bus in 1 s | 2 s |
| E9 | Soak: mixed traffic with echo | PASS | 120 s at 185 f/s with echo: 22 200 sent, received, echoed and verified; 0 loss; TEC/REC 0; 0 error frames | 22 300, same |

## Findings

### Hardware: nothing to fix

- **Transceiver.** FD data phase at 1, 2, 4, 5 and 8 Mbps in both directions with clean counters to 5 Mbps (D2, D3), and the board's own external loopback through the TCAN3414DR is error-free at every rate including 8 Mbps (D6). At 8 Mbps against the adapter, two data-phase bit errors on the board's own transmissions were retried and every frame delivered, which is exactly what the MAX33041E did in the same test. Since the board alone is clean at 8 Mbps and the errors only appear with the adapter's 5 V, 5 Mbps-class transceiver on the other end of the bus, they belong to the two-transceiver bus at a rate above anything a vehicle uses, not to the new part. The scope confirms the driver is well inside its datasheet (below).
- **Standby and wake-on-bus.** The TCAN3414DR's standby is different in kind from the MAX33041E's: the bus is weakly biased to ground, the main receiver is off, and RXD stays high until the low-power bus monitor has seen a complete ISO 11898-2:2016 wake-up pattern (filtered dominant, filtered recessive, filtered dominant, each longer than tWK_FILTER of 0.5–1.8 µs, all within tWK_TIMEOUT of 0.8–6 ms). Only then does RXD go low on the next filtered dominant. The datasheet says any classic frame at 500 kbps or slower contains a valid pattern, and E6 confirms it: with the controller in Sleep and STB high, the first 500 kbps frame set WAKIF and pulled CAN_INT low, 3 ms after the host's send timestamp. The existing `hw_can.c` sleep path (XSTBYEN, GPIO0) needs no change for the new part. Two things to remember: a 1 Mbps bus needs two back-to-back dominant bits to satisfy the filter, and the frame that wakes the transceiver is not received by the controller, which is also true of the MAX33041E and of the MCP2518FD's own wake behaviour.
- **SPI through the series resistors.** 10 240 bytes of message RAM written and read back with five patterns plus 200 timed transactions, zero errors, at both the production timing (131 kbit/s on the wire) and the direct-GPIO timing (894 kbit/s). The 220 Ω and 1 kΩ resistors do not limit the link at these speeds.
- **Controller and crystal.** Every bit rate from 125 k to 1 M works with clean counters. The adapter could be pulled 2.44 % low or 2.56 % high before the link broke, symmetric to within the ±0.3 % resolution of the test points, which rules out a gross crystal error but says nothing at the ppm level. Host sample points from 60 % to 95 % all worked against the board's 80 %.
- **Rail switching.** PP3V3_CAN drops below the sense threshold 22 ms after CAN_EN goes low and the controller is back in Configuration mode with its oscillator running 24–25 ms after it goes high, five times out of five.

### The SPI driver is the throughput limit

| direction, frame | production SPI | direct GPIO |
|---|---|---|
| receive, 8-byte classic | 500 frames/s lossless, overflow from ~550/s | 3340 frames/s, overflow from ~3750/s |
| transmit, 8-byte classic | 320 frames/s (375 with DLC 0) | 2150 frames/s (2535 with DLC 0) |
| receive, 64-byte FD | 500 frames/s | 2900 frames/s (bus limited) |
| transmit, 64-byte FD | 152 frames/s | 1050 frames/s |
| echo round trip | 6.6 ms median | 2.6 ms median |

These are the v3.1 numbers within run-to-run noise, which is the point: the transceiver is not in the path that limits any of them. A saturated 500 kbps bus carries about 4000 to 4400 eight-byte standard-ID frames a second; passenger-car powertrain buses run at 40 to 80 % load, 1600 to 3500 frames/s. With the production driver the 32-frame RX FIFO fills in 8 to 9 ms of bus-rate traffic and frames are lost, with the overflow flag raised reliably. Direct GPIO with no waits reaches roughly 75 % of the bus maximum with identical data integrity. Whatever the driver, hardware acceptance filters (E4) should reduce the load to the IDs of interest and the RX FIFO should be the full 32 objects, not the 4 used by the boot-time test.

### Mode choice on a vehicle bus

- **FD tolerance.** A controller in Normal CAN 2.0 mode error-flags every FD frame (D5), destroying it for every node on the bus while its own receive error counter climbs. Normal FD mode accepted classic frames in every test, so it is the safer default; Listen-only is safest if the tracker only observes.
- **Listen-only** is genuinely passive (E3). On the two-node bench a lone transmitter's frames only become valid to the passive listener once that transmitter is error-passive; on a real bus other nodes ACK.
- **One-shot transmit** works, but an aborted message stays in the FIFO with TXREQ clear and blocks everything behind it until the FIFO is reset (E1).
- **Error counter arithmetic (E1).** With no partner and retry on, TEC climbs by 8 per attempt until 128, where the error-passive exception stops ACK errors counting. It read 126 once the partner was back: the ceiling less the two frames delivered before the read. After the following burst it read 15, a fall of 111, which is the 9-frame reply to the first read, the 100 burst frames and the 2-frame burst reply: one decrement per successful transmission, as the specification says. The one-shot phase's TEC of 88 is 11 single attempts at 8 each.

## Oscilloscope

Rigol DHO814, 10× probes on flying leads soldered to the transceiver's CANH, CANL, TXD, RXD and GND pins, 500 mV/div on the bus channels. Whole 1 Mpt records were read over SCPI and every single-bit-wide run in the data phase was measured; the differential was recomputed from the raw samples. Board-transmit shows the TCAN3414DR's driver; adapter-transmit shows what the board has to decode. Levels are read 75 % into the bit, the earliest sample point in use on either side (board 80 % nominal and at 2 Mbps, 75 % at 5 Mbps; adapter 80 % nominal, 75 % data phase). In the board-transmit captures the adapter's ACK bit is also present, one dominant bit per frame from the far end at 3.5 / 1.4 V single-ended, so the persistence eyes show both drivers.

| case | bits | dominant at 75 % sample point, min / mean | recessive | overshoot / undershoot | bit width spread | 10–90 % edge |
|---|---|---|---|---|---|---|
| 500 kbps, board TX | 140 | 1.96 / 1.99 V | 0 V | +2.18 / −0.36 V | ±13 ns | 30 ns |
| 500 kbps, adapter TX | 334 | 1.96 / 2.11 V | 0 V | +2.17 / −0.02 V | ±5 ns | 78 ns |
| FD 2 Mbps, board TX | 590 | 1.96 / 1.98 V | 0 V | +2.17 / −0.36 V | ±14 ns | 27 ns |
| FD 2 Mbps, adapter TX | 2411 | 2.08 / 2.11 V | 0 V | +2.17 / −0.03 V | ±3 ns | 78 ns |
| FD 5 Mbps, board TX | 495 | 1.96 / 1.99 V | 0 V | +2.17 / −0.36 V | ±13 ns | 27 ns |
| FD 5 Mbps, adapter TX | 3484 | 1.96 / 2.00 V | +0.05 V | +2.17 / −0.03 V | ±4 ns | 71 ns |

Single-ended, board transmitting: recessive CANH = CANL = 2.2 V; dominant CANH 2.9–3.0 V, CANL 1.0 V, a 2.0 V differential that the datasheet puts at 1.5–3.0 V into 60 Ω. The differential edges measure 26 to 31 ns 10–90 %, in the datasheet's 30–57 ns rise and 30–50 ns fall bands and the scope's own resolution is part of that; the MAX33041E's were under 10 ns. Each dominant-to-recessive transition still has a brief undershoot, now to about −0.36 V rather than −0.65 V, and a short ring that appears equally on both lines and cancels in the difference. Slower edges and half the undershoot is the direction that helps on a real harness, and it costs nothing at 5 Mbps: a 200 ns bit is flat within 150 mV about 40 ns after its edge, so the level is settled for 110 ns before a 75 % sample point. The TCAN3414DR has no slew-rate-limited mode, so this is the only driver it has. After every dominant bit both lines drop together to about 1.4–1.6 V and drift back to 2.2 V over several microseconds with zero differential: the receiver bias network recharging, normal, and confusing on a single-ended trace.

500 kbps rising edge at 100 ns/div

*classic_edge: 500 kbps, 100 ns/div, two recessive-to-dominant edges superimposed: the board's (CANH to 3.0 V, CANL to 1.0 V, about 50 ns single-ended) and the adapter's ACK bit (3.5 / 1.4 V, slower). Both start from the 2.2 V recessive bias.*

500 kbps persistence eye at 1 µs/div

*classic_eye: 500 kbps eye, 1 µs/div, infinite persistence. The heavy traces are the board's driver, the thin ones at 3.5 / 1.4 V the adapter's ACK; the slow ramps after a bit are the common-mode recovery, identical on both lines.*

FD frame at 50 µs/div

*fd2m_frame: One FD frame at 50 µs/div: sparse 500 kbps arbitration bits from the start-of-frame, then the dense 2 Mbps data phase.*

FD 2 Mbps eye at 250 ns/div

*fd2m_eye: FD 2 Mbps data phase, board transmitting, 250 ns/div. 500 ns bits, flat within 40 ns of each edge.*

FD 5 Mbps eye at 100 ns/div

*fd5m_eye: FD 5 Mbps, board transmitting, 100 ns/div. 200 ns bits, 27 ns edges; the eye at the 75 % sample point is fully open.*

FD 5 Mbps eye, adapter transmitting

*fd5m_host_eye: FD 5 Mbps, adapter transmitting, 100 ns/div: what the board receives. 71 ns edges, still about 80 ns of settled level before a 75 % sample point.*

FD 5 Mbps frame at 50 µs/div

*fd5m_frame: A 5 Mbps FD frame at 50 µs/div, board transmitting: about 150 µs from start of frame to the ACK bit for 64 bytes (the taller pulse at the end is the adapter acknowledging).*

Transceiver loop delay

*loopdelay_fall: Loop delay, 50 ns/div: TXD (magenta) falls at 0, the bus follows 40 ns later, RXD (blue) 86 ns later. The ringing on the logic pins is the probe ground leads.*

### Transceiver loop delay

Probes on the TCAN3414DR TXD and RXD pins, 232 edges each way at 500 kbps, spread under ±2 ns.

| edge | TXD → bus | bus → RXD | TXD → RXD | datasheet, TXD → RXD |
|---|---|---|---|---|
| recessive → dominant | 40 ns | 46 ns | 86 ns | 95 typ, 180 max |
| dominant → recessive | 53 ns | 54 ns | 107 ns | 120 typ, 180 max |

A little faster than typical and well inside the maximum. The dominant bit starts 40 ns late on the bus and ends 53 ns late, so it is lengthened by 13 ns, 6.5 % of a 5 Mbps bit; the datasheet's pulse skew is 18 ns typical, 28 ns maximum, and the MAX33041E measured 13 ns the other way (shortened). The single-bit widths in the table above show it directly: dominant bits at 5 Mbps measure up to 213 ns and recessive ones down to 187 ns. Normal for a CAN FD transceiver, and the MCP2518FD's TDC in auto mode measures the loop delay itself; these are the numbers for a manual offset if auto is ever disabled.

## MAX33041E vs TCAN3414DR

Both are 3.3 V CAN FD transceivers in the same SOIC-8 pinout with an active-high standby pin, and the board is otherwise unchanged. What differs, from the datasheets and from the bench:

|  | MAX33041E (v3.1) | TCAN3414DR (v3.4) |
|---|---|---|
| Rated data rate | 5 Mbps | 2 / 5 Mbps (EMC certified), 8 Mbps in simple networks; bit-time symmetry specified at all three |
| Dominant differential at the sample point, board TX, worst of ~500 bits at 5 Mbps | 1.81 V | 1.96 V |
| Differential edge, 10–90 % | <10 ns (scope-limited) | 27–30 ns (datasheet 30–57 ns) |
| Undershoot after a dominant bit | −0.65 V | −0.36 V |
| Loop delay TXD→RXD, rec→dom / dom→rec | 72.5 / 60 ns (max 140) | 86 / 107 ns (max 180) |
| Loop-delay skew | 13 ns, dominant shortened | 21 ns, dominant lengthened 13 ns (max 28) |
| 8 Mbps against the adapter | 2 bit errors, retried | 2 bit errors, retried; own loopback clean |
| Slew-rate-limited mode | yes, resistor on STBY | no |
| Standby | low-power receiver passes bus edges to RXD | ISO 11898-2:2016 wake-up pattern; RXD high until a valid WUP; bus biased to ground; 10 µA typ |
| Wake seen by the controller (E6) | 9 ms after the first frame | 3 ms after the first frame |
| Bus fault protection / common-mode range | ±40 V / ±25 V | ±58 V / ±30 V |
| TXD dominant timeout | yes | 1.2–4.0 ms |
| Price | ~3× | 1× |

Nothing in the bench or on the scope argues for the more expensive part. The TCAN3414DR's slower edges and smaller undershoot are the right direction for emissions on a real loom, which was the only EMC worry with the MAX33041E, and it needs no slew-limited mode to get there; its longer loop delay is absorbed by the controller's automatic TDC; its wider protection and common-mode range are simply better; and its standby needs nothing from the firmware that the old part did not.

## Agent bugs found on the way

The three fixed on the v3.1 bench (FD TSEG2 off by one at 2 and 4 Mbps, message-RAM overrun with timestamps on, one-shot FIFO reset) stayed fixed. One more was in the agent's one-shot abort detector: it read the TX FIFO's empty flag and then TXREQ as two separate SPI transactions, about 1 ms apart on the production bit-bang, and a frame in flight completing between the two reads looked exactly like an aborted one-shot message. The agent then reset a healthy FIFO, counted the frame as failed and skipped a sequence number, so every other frame of a burst could go missing with the slow SPI at some bit rates, always with TEC 0 and the host receiving exactly the frames the agent said it sent. That is the origin of the v3.1 report's unexplained "50 of 100 frames sent" in E1. The fix reads TXREQ first: hardware only clears it once the FIFO is empty, and nothing queues a frame between the two reads, so TXREQ-clear followed by not-empty can only be an abort. A production driver that polls for aborts needs the same ordering.
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

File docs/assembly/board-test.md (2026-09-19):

# Board test

Test a newly assembled board in four stages, stopping to fix anything unexpected before moving
on:

1. unpowered checks, without the Connect Kit;
2. first power-up, still without the Connect Kit;
3. power-up with the Connect Kit fitted;
4. the interactive firmware board test, which exercises every fitted subsystem.

Stages 1 and 2 need only a multimeter and a current-limited supply. Stage 4 also needs the
firmware toolchain.

## Test points

v3.4 has seven test points. Readings below are with 12V applied to the board.

| Test point | Net | Expected |
|---|---|---|
| S12TP1 | GND | Ground reference for every reading |
| S12TP2 | PP4V2 | 4.2V whenever the input is powered: the buck, the OVP MOSFET S11Q1 and the ideal diode S11U1 are all passing the rail |
| S12TP3 | PP3V3 | 3.3V only with the Connect Kit fitted - it comes from the Connect Kit |
| S12TP4 | PP3V3_GPS | 0V until the firmware switches the GPS rail on |
| S12TP5 | PP3V3_CAN | 0V until the firmware switches the CAN rail on |
| S12TP6 | PP3V3_K | 0V until the firmware switches the K-wire rails on |
| S12TP7 | PP12V_K | 0V until the firmware switches the K-wire rails on |

The unprotected buck output has no test point on v3.4; measure it at the non-ground pad of S6C5.

## Stage 1: unpowered checks

With no power applied and the Connect Kit **not** fitted:

1. Measure resistance from every test point to S12TP1. Find and fix any short before continuing.
2. Check for continuity from the 12V rails - Molex pin 4, pin 5 and S12TP7 - to the 4.2V and 3.3V
   test points. There must be none.
3. Check for shorts between every pair of adjacent pads on the ASM330LHHXTR accelerometer, for
   example between SDA and SCL, or SDA and 3.3V.
4. Do the same for the INA228, the LT8609A and any interface chips you placed.
5. Check that the centre pin of each SMA connector is not shorted to its outer casing. If it is,
   that antenna will not work.

## Stage 2: first power-up without the Connect Kit

The board is fed through the Molex connector: pin 2 is ground, pin 4 the permanent 12V and pin 5
the ignition input. Pins 3 and 6 are the interface bus lines and pin 1 is unused. See the
[vehicle connector pinout](../reference/hardware.md#vehicle-connector-pinout).

1. Set the bench supply's current limit to 50mA.
2. Apply 12V to both the permanent (pin 4) and ignition (pin 5) inputs and watch the current as you
   switch on. If it immediately pins at the limit, switch off quickly: there is a short to find.
   If it jumps up and then settles close to 0, that is normal - the buck converter going to sleep.
3. Check that S12TP2 reads 4.2V.
4. Check that S12TP4, S12TP5, S12TP6 and S12TP7 all read 0V. The load switches should be off, since
   nothing is driving their enable signals.
5. Turn the board over and measure the voltage on every pin of both 20-pin headers. Every pin
   should read below 3.3V, and none may read 12V. Nothing on the headers is powered until the Connect
   Kit supplies the 3.3V rail; the 4.2V supply reaches the Connect Kit through the power lead in S1J4,
   not through the headers.

!!! danger "Any 12V on a header pin means stop"
    Do not fit the Connect Kit to a board that shows battery voltage on any header pin. It would be
    destroyed.

## Stage 3: power-up with the Connect Kit

Carry out the [final assembly](assembly-guide.md#final-assembly) steps, then:

1. Apply 12V again with the current limited to 50mA. At any sign of a short, switch off
   immediately. If the current does not pin at the limit, chances are the board is built
   correctly.
2. Once the firmware is running, it switches rails on as it needs them, and the matching test
   point should then come up: S12TP4 (GPS) to 3.3V, S12TP5 (CAN) to 3.3V, S12TP6 (K) to 3.3V and
   S12TP7 (K) to 12V.

A short after one of the auxiliary rail load switches will not show up until the firmware enables
that rail. The board senses each rail, so the firmware detects a rail that fails to come
up, and the firmware board test below checks every one.

## Stage 4: the firmware board test

`firmware/board_test.sh` builds and flashes a test firmware that walks you through every fitted
subsystem over the serial console: rail switching, ignition sensing and wake, battery voltage, the
accelerometer, GPS, the modem and the interface loopbacks.

### What you need

- The software and the clone of the repository from
  [Board setup prerequisites](../board-setup/prerequisites.md). Updating the Connect Kit's
  interface firmware ([Updating the Makerdiary firmware](../board-setup/makerdiary-firmware.md))
  is not needed for the test, but is needed before the board goes into use, so you may as well do
  it first.
- A USB-C data cable to the Connect Kit. The script flashes over it and uses its serial console.
- A bench lead with a **switch in the ignition feed** (pin 5), so you can turn the ignition on and
  off while the permanent 12V stays connected.
- An **adjustable supply**: one test asks you to raise the voltage by at least 1V and then lower
  it by at least 1V.
- The supply's **current limit raised to around 300mA**. The 50mA limit of the first power-up
  catches shorts, but a modem transmitting at full power averages up to about 45mA from the 12V
  input, with bursts above that, and a supply that hits its current limit makes the board brown out
  and reset.
- A SIM card in the Connect Kit and an antenna on both SMA connectors, with the GPS antenna able
  to see the sky. The GPS test searches for an unassisted cold fix, which can take several minutes.
- `CONFIG_APP_APN` set to your SIM's APN in `firmware/local.conf`.

!!! note "Set your APN before running the test"
    The script uses the first APN it finds in `local.conf`, then the Makerdiary profile overlay,
    then `prj.conf`. `prj.conf` always sets one (`sensor.net`), so without an APN in `local.conf`
    the modem test silently uses that value rather than asking - and it is unlikely to be the APN
    for your SIM.

A one-line `firmware/local.conf` is enough for the test:

```text
CONFIG_APP_APN="your.apn"
```

### Running the test

```sh
# in firmware/
./board_test.sh
```

The script asks three things:

1. **Board version.** Choose the revision you built: **v3.4** for a v3.4 board.
2. **OBD interface**: none, CAN or K-wire (ISO 14230), matching the parts and pads
   you fitted.
3. **APN.** It shows the APN it found and where it found it. It only asks if it finds none, and
   leaving the answer empty skips the modem test.

It then writes the answers to `board_test.conf` (gitignored), builds the firmware with
`CONFIG_APP_BOARD_TEST=y`, flashes it with `./flash.sh`, opens a `screen` session called
`l0destar-test` on the console port at 115200 baud - the first `/dev/cu.usbmodem*` port on macOS,
or the Connect Kit's `-if00` port under `/dev/serial/by-id/` on Linux - resets the board and
attaches you to the console. Press **Enter** to start the tests.

`local.conf` is not layered into the test build, but four values are read from it:
`CONFIG_APP_APN`, `CONFIG_APP_DEMO_MODE` (masks the GPS coordinates in the output),
`CONFIG_APP_BOARD_TEST_HIDE_COORDS` (drops them altogether) and `CONFIG_APP_CRASH_THRESHOLD_MG`
(the impact threshold, 1200mg by default for the test - a firm bang on the desk is 1.5-3g). The
test build also limits network registration to 180 seconds.

Useful `screen` keys: `Ctrl-A [` scrolls back, `Ctrl-A d` detaches (reattach with
`screen -r l0destar-test`) and `Ctrl-A k` kills the session. The console output is logged to
`firmware/screenlog.0`.
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

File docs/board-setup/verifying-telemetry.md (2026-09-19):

# Verifying telemetry

With the device enrolled, check the whole path - device, network, server, database and web interface - while the board is still on the bench, where problems are easy to see and fix.

Keep a console open on the device (see [minimal config and initial flashing](initial-flashing.md#watch-the-console)) and a shell on the server.
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

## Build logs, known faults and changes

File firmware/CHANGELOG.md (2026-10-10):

# Changelog

## 0.4.73

### The ignition-off record no longer waits for GPS underground
At 17:28 on 2026-10-10 the car drove into the same underground car park as
that morning and went dark for the whole 18-minute stay.  The records came
in as it drove out, none of them lost, but the ignition-off record was 18
minutes late.  A bench replay of the stay showed why:
- **A fix wait ran on past the key-off.**  The ignition is only looked at
between collections, so a key-off during a cold search waited out its
300 s.  Then the ignition-off record waited out another 300 s cold search
before falling back to the last known position.  The bench sent it 10
minutes after the key went off.  Now a fix wait ends when the ignition
changes, once the change has held past the crank dropout (5 s) or the
backup module's wake pulse (1.5 s).  A record that has to go out gives the
fix 15 s (`TRANSITION_FIX_WAIT_MS`).
- **A six-minute-old GPS speed started coast-to-stop.**  The car's last fix
before going underground said 5.3 km/h.  At key-off the ECU had no power,
so that speed was taken as the current one, and coast-to-stop began.  The
coast only ends after a send, which a collection with no fix never
reaches, so the unit stayed awake with GNSS running, never reaching the
sleep path that resends.  The ignition-off record, lost with the
registration, was held until the key came back on, though the modem had
registered again within a minute.  The GPS speed now only counts while the
fix is under `SPEED_FIX_MAX_AGE_MS` old, and a collection with no fix ends
the coast.
- **A key-off whose record cannot be sent no longer keeps the unit awake.**
With the modem registered but sends failing locally (a dead socket, a data
connection gone under a live registration, a failed lookup), the
ignition-off record was collected and sent again and again until modem
recovery restarted the radio, 10 minutes on.  Each pass added another copy
of it to the backlog.  The record is in the backlog after the first
failure, so the unit now sleeps, and `do_sleep()`'s delivery and the timed
wakes carry it from there.

## 0.4.72

### The server's address is looked up again when the server goes quiet
The address of `APP_SERVER_HOST` is still looked up once per boot and kept,
so a send costs no lookup.  Kept for good, though, a moved server would be
sent to until the next reboot, and the update notice that could have forced
one rides on the replies that no longer come.  Now three sends in a row with
no reply, all made with the modem registered and the first over 5 minutes
ago, close the socket and look the name up again.  Sends made without a
registration don't count, so a dead zone or a TAU reject never triggers it,
and 5 minutes is well past the 38 s stall seen on a registered link.  If the
lookup fails or finds the same address, the address in hand is kept and the
number of sends before the next try doubles, up to 48.  Any reply resets it.

## 0.4.71

### A parked unit falls back to NB-IoT where LTE-M does not reach
At 09:44 on 2026-10-10 the car drove into an underground car park at 7 km/h
and went silent: no ignition-off record, and nothing could reach it until it
was driven out.  LTE-M only is still the rule.  But when a parked search on
LTE-M runs out its `APP_NETWORK_SEARCH_TIMEOUT`, the modem now switches to
LTE-M plus NB-IoT, LTE-M preferred, and gets a fresh window with the report
still owed.  This happens on a timed wake, or at sleep entry when the search
had already run out on the way in.  The fallback stays on through later timed
wakes and goes off at key-on, so a drive never runs on NB-IoT.
`APP_NBIOT_PARKED_FALLBACK` (default y).

At home the bench attaches on EE NB-IoT (B3) and Vodafone NB-IoT (B20).
NB-IoT copes with about 8 dB more loss than LTE-M; whether that is enough
for that car park is for the car to show.
- **Key-on cost only after a dead-zone stay.**  `%XSYSTEMMODE` needs the
radio offline, so going back to LTE-M with the modem up is CFUN=4, the mode,
then a full bring-up.  Measured at 3.3-5.3 s with AT commands, and 4.1 s
from key-on to GNSS start in the firmware.  Otherwise a key-on still resumes
from PSM at no cost.  With the radio off the mode only applies at the next
bring-up, for nothing.
- **The CFUN=4 is waited for in watchdog-fed slices** (`nrf_modem_at_cmd_async`),
capped by `APP_NBIOT_OFFLINE_CAP_S` (90 s).  The detach took about 60 s once
on the bench.
- **Bench test** with `APP_DEBUG_NBIOT_TEST` (LTE-M held to an empty band
until the fallback is used, NB-IoT preferred, a simulated key-on 90 s after
the report): after 301 s on LTE-M the fallback came on.  It took 24 ms to go
offline, then 6 s to register on EE NB-IoT.  The owed report reached the
server with `rat=NBIOT`, and the modem stayed in PSM on NB-IoT.  At the
simulated key-on it went offline in 1.2 s, registered on LTE-M 2.7 s later
and started GNSS 4.1 s after the key, with the first ignition-on record at
the server 8 s after the key.

## 0.4.70

### Band 3 is back, on trial
EE's LTE-M is on B3 only here, and B3 had been locked out since EE kept
winning operator selection over O2 and Vodafone on B20.  On 2026-10-10 the
bench, unlocked at home, scanned all three.  O2's home cell 135829634 (B20) is
the strongest at -102 dBm, but with an SNR of -4 dB the modem needs every
downlink four times and rates it poor (`%CONEVAL` energy estimate 6).  EE's
cell 3167234 (B3) reads -110 dBm, but at +3 dB SNR, with no repetitions and a
normal estimate (7).  `CONFIG_LTE_LOCK_BAND_LIST` is now `"3,8,20"`, so the
modem can choose EE.  Every move between EE and O2 costs a full reattach after
an EMM cause 9 reject (the bench saw one switching O2 -> EE), so this is a
trial: if rejects or gaps on the road go up, set it back to `"8,20"`.

### A record lost with the registration is resent when the network is back
At 23:14 on 2026-10-09 the parked car's hourly report went out, and 6 s later
the registration was lost: the modem had moved to TAC 12296 cell 289044, where
the network rejected it (cause 9) and discarded the queued datagram.  The
record went back into the backlog after 8 s unanswered.  The wake had already
checked for a registration before waiting for replies, found one and owed
nothing, so it powered the modem down.  The record reached the server with the
00:15 report, an hour late.  Now, if records are still in the backlog once
the replies have been waited for and the network has gone, the report is owed
like an unsent alert.  The loop keeps the modem searching through
`APP_NETWORK_SEARCH_TIMEOUT` and sends as soon as it registers.

## 0.4.69

### An update check on a dead link no longer runs the watchdog out
At 13:05 on 2026-10-04 the car's hourly wake found 0.4.68 on offer and asked
for the manifest.  The link was dead, so the request ran its full 30 s
timeout and failed (-116), and the failure handling after it took the time
since the last kick past 32 s.  The task watchdog fired ("no kick for 32s —
resetting"), and the main loop kicked again inside the two seconds before the
hardware fallback would have reset the SoC.  Nothing reset, and the update
went in at the next key-off, but that was two seconds from a reboot.
- **A kick straight after the request,** whichever way it ends, so what
follows starts a fresh window.  `fota_check()` already kicked just before it.
- **`APP_FOTA_MANIFEST_TIMEOUT_S` is 25 s, at most 25.**  The request holds
the loop for its whole timeout, DNS included, with no kick inside, so 30 s
left two seconds of a 32 s window.  A `BUILD_ASSERT` keeps 7 s.  Not lower:
a check over a working link took 15.6 s on the bench.

### The track through a gap is measured, not guessed
GNSS gets nothing while LTE holds the radio, and every send holds it.  Most
cells here let go about 2.5 s after the reply; the TAC 12296 cells keep it for
about 10 s, and no cell here honours release assistance (every `%RAI` report
the bench has logged reads `as_rai=0, cp_rai=0`, so `SO_RAI` changes nothing).
On those cells a drive is three one-second fixes every 14 s joined by straight
lines 100-180 m long: all of the 22:49 drive on 2026-10-03, at half the record
rate of a drive on TAC 4096.  A rejected tracking-area update blinds the
receiver for longer still: at 22:37 the same evening it was 24 s, then 15 s
more for the re-attach's own connection, and the replay drew 214 m in one
straight line across it.  The firmware cannot shorten either.

So it now measures what it cannot see.  The record that ends a gap of 2.5-60 s
on the move carries `mv=<gap>:<v0>:<steps>:<end>`: the ECU's road speed and
the gyro's heading change for each second of the gap.  The server fits that
path between the two fixes and the replay draws it dashed.  See `src/motion.c`.
- **Heading change from the gyro.**  The IMU's FIFO already batches the gyro
at 26 Hz whenever the unit is awake.  Every drain now feeds the samples,
projected onto gravity (the accel words averaged over ~20 s), into a running
heading noted at each whole second.  The fix wait's tick and the top of every
main-loop pass drain it, so the ring (about 7.4 s at 26 Hz, measured on the
bench) does not overrun in an ordinary cycle.  One that does — the loop held
up for longer than that, as by the key-on fault-code read — or a restarted
FIFO starts the log again, and a gap across the hole gets no field.  Checked against the car's records before it was written:
over 2,084 one-second pairs the GNSS heading change was -1.0 times the
projected gyro, the sign a right-handed gyro gives with gravity pointing up.
The car's unit sits 19 degrees off level with Y up, so Z alone would not do.
- **Speed from the ECU.**  Every K-line speed reading is kept with its time,
and each second's is interpolated between the readings either side, which
bridges the poll's pause for a send.  Without an ECU the field carries
headings alone and the server takes speeds from the fixes.
- **The fix's real moment.**  `gnss_fix.epoch_ms` is the uptime the receiver
delivered the fix at.  `fix_uptime_ms` is when the loop picked it up, which a
K-line reopen can make 4 s later.
- **Two bytes a second, never at a record's expense.**  A 3-4 s gap between
batches costs 15-17 bytes, a 12 s one 33, about 1.5 KB per ten minutes of
driving.  The batch's flush threshold leaves the field out
(`data_motion_bytes()`), so it never makes a batch go early and cost fixes.
The field is built to fit a backlog slot (`APP_DATABUF_REC_MAX`) with the
record, and `send_data()` drops it from a batch that would not fit a datagram.
- **An impact's profile stays in the FIFO.**  The FIFO gives each sample once,
so nothing drains it for the dead reckoning while an impact is waiting for
`crash_check()`; the impact's own drain feeds the dead reckoning instead.
The pre-impact history is now whatever has come in since the last drain, a
second or so in a cycle, rather than the whole ring; the peak and everything
after it are there as before.

`APP_DEAD_RECKONING` (default y) turns it off.  A host harness ran the real
`motion.c` through simulated drives with the car's mounting, gyro noise and
bias, a 1.5% IMU clock error, irregular drains and holes in the ECU readings,
and decoded the fields with the server's `deadreckon.py`: the fitted path was
within 0.3-4.5 m of the truth where the straight lines it replaces were
21-38 m off.

### A long gap between fixes says why
At 20:28 on 2026-10-03 the car went 31 s between fixes at 24 mph and left no
trace of why: no registration loss, no starved-receiver warning.  A warm fix
wait that LTE blocks outright never logged anything.  Now fixes 20 s or more
apart (`APP_FIX_GAP_WARN_S`), with the key on and a fix at either end moving
at 10 km/h or more, get one WRN line: how long the loop waited for the fix,
how long GNSS was blocked by LTE and an RRC connection held, how many epochs
the receiver flagged as short of radio time, the cell before and after, and
whether registration was lost.  That separates a radio-blocked gap from one
the loop spent elsewhere.  At most one a minute, the next saying how many were
held back.  Run over the car's records from 2026-09-25 it would have fired 14
times in eight driving days, never more than five in a day.  Drive starts are
not counted: the record at key-on is the stored position, not a fix.

## 0.4.67

### An unfitted interface's rail senses are left disconnected
The parts that drive each rail-status line belong to its interface: S7R3/S7R4
for CAN, and S7R8/S7R9 plus the S7Q1/S7R7 inverter for the K line.  A board
built with one interface leaves the other's sense lines as bare nets, but
`hw_domain_init()` made all four connected inputs on every v3.1+ board.  So a
CAN-only board had P0.00 and P0.31 (PP3V3_K_ST, PP12V_K_ST) floating with
their input buffers on.  A K-line board without the CAN parts had P0.22
(PP3V3_CAN_ST) the same way.  Nothing reads them on such a board, and a
floating connected input can only cost current: Nordic give no figure for
it, and it depends on where the node drifts.  A sense line is now an input
only when `APP_BOARD_HAS_CAN` or `APP_BOARD_HAS_KLINE` says its interface is
fitted.  Otherwise it is set to the reset state (input disconnected), written
through the HAL because `GPIO_DISCONNECTED` leaves alone a pin the driver has
not configured.  It is not driven low or pulled down: on a board with both
interfaces fitted, S7R7 holds PP12V_K_ST at 3.3 V and either would draw ~30 uA.
The other K pins needed nothing.  On a CAN build K_TX, K_RX, K_SLEEP and
L_SEND are never configured, and K_EN is driven low, so the K pull-downs
missing on such a board (S1R5, S10R5, S10R6, S10R9) cost nothing.

## 0.4.66

### Setting off is not a tow
At 10:01 on 2026-10-03 the car sent "tilt 24.5deg - possible tow/jack" as it
pulled away, and at 23:37 on 2026-10-01 it sent "movement: 17.6deg tilt" the
same way.  Both times the next record had the key on and the car rolling, at
21 km/h and 4 km/h on the ECU.  A sleep pass checked tilt, then the ignition,
then movement, and the tilt debounce (2 s) and the movement confirm (up to
10 s) can each hold a pass that long.  A driver who gets in, starts up and
drives off inside one pass was measured as a parked car being tilted or
moved: the tilt check compares single accelerometer reads with the parked
attitude, and pulling out of a junction is many degrees of that.
- **The ignition comes first in every pass.**  A pass that starts with the key
on goes straight to the drive without looking at tilt or movement.
- **A key that comes on during the pass ends it.**  After the tilt debounce,
and during and after the movement confirm, the line reading on (or an edge
the interrupt latched) drops the alert and leaves the key to the next pass.
The confirm now stops at the first 100 ms poll that sees it, rather than
running out its 10 s.  No parked-impact fallback is sent from such a pass
either.
- **A key turned straight through to the starter is a key.**  The car's sense
line drops out while the starter turns.  If that happened inside the 200 ms a
wake waits for, the pass logged "too short for a key" and went on to the tilt
and movement checks.  A short pulse now gets `IGN_CRANK_MAX_MS` (5 s) for the
line to come back before it is ignored.

### A crank is not a low battery
At 10:16 the same day the car sent "low battery: 9.82V" as it was started
after an 11-minute stop.  The key-on woke it, and when IDLE first looked a
second or two later the starter was turning and the sense line was out.
IDLE took that for a short key cycle: it built an ignition-off record at the
bottom of the sag and went back to sleep, and the same key woke it again
four seconds later.  The 60 s settle guard (`BATTERY_WARN_SETTLE_S`) did not
hold the alert back, because it counted from the last record that said the
ignition went off, the key-off eleven minutes earlier.
- **IDLE gives the line `IGN_CRANK_MAX_MS` to come back** before it reports a
short key cycle after a key-on wake.  A crank no longer produces a record, a
sleep and a second wake.
- **The settle time also counts from the last time the line read on**,
wherever it was read (`ignition_last_on_ms()`).  So no reading taken within a
minute of a key-on alerts, by any path.  The backup-power alert uses the
same guard.

### Movement alerts give the real deviation
Every movement alert from the car has said about 3000 mg (3010 on 2026-10-01,
3225-3484 in September), however gently the car moved.  The figure was read
straight after `accel_irq_disable()` moved the IMU from ±2 g low-power to
±8 g, before it had a valid sample at the new setting.  On the bench, a read
at that point was wrong on 5 tries out of 8 (11-14 g from a unit at rest),
while the same read taken at ±2 g just before the switch was 1-18 mg every
time.  The figure is now read before the switch, at the ±2 g the confirm ran
at.

## 0.4.65

### No more phantom impacts from FIFO samples read at the wrong full-scale
The IMU's FIFO ring was never emptied when the accelerometer changed range,
and the drain converts every sample at the range in force when it runs.  So
after a confirmed-movement wake in sleep, which goes to ±8 g and re-arms at
±2 g, the next drain read the ±8 g samples at a quarter of their size: a still
unit came out at ~250 mg, a deviation from 1 g of 744 mg, which the
parked-impact path takes for a hit.  The reverse happened on a wake from
sleep, where the awake ring started out holding ±2 g samples that it read at
±8 g, so a still unit read 4.1 g.  The IMU also keeps its FIFO, still
batching, through an MCU reset.  `accel_enable_wake_int()` and
`accel_fifo_enable()` now go through bypass, which empties the ring, before
starting it again.  On the bench, the two switches read 744 mg over 3154 ms
and 4.1 g over 3914 ms before the change, and 31 mg and 26 mg with nothing
over threshold after it.

## 0.4.64

### A power cut is reported, with or without the module's wake pulse
The first bench tests of the inline battery backup, on 2026-09-30, found two
things wrong with how a sleeping tracker learned of a cut.  The module fires
its ignition pulse as the car rail falls through about 10.06 V, but its
switchover comparator watches the car side of its ideal diode, and at that
moment the tracker's own rail is still held at the car's level by its input
capacitance: 11.31-11.35 V at the pulse, in the backup band 4.4-4.7 s later.
0.4.47 read the rail at the pulse and required the band, so it could never
recognise a cut, and without `APP_BACKUP_SUPPLY` a pulse that had ended by
the 200 ms re-read left nothing in the log at all.  Separately, IGN passes
straight through the module and the pulse goes in through 10K, so a bench
lead holding pin 5 at ground for "ignition off" shorted it; with pin 5 open
the tracker saw 482 ms and 706 ms pulses.  In a car the ignition wire's own
loads hold it down the same way, which is a module fix (an isolation diode),
so the firmware no longer depends on the pulse.
- **A pulse is told from a key by how long it lasts.**  With
`APP_BACKUP_SUPPLY`, the line still on 1.5 s after the interrupt
(`BACKUP_PULSE_MAX_MS`) is a key, timed from the interrupt itself.  So a
key-on from sleep is recognised after 1.5 s instead of 200 ms.  Without the
option the 200 ms debounce is unchanged.
- **Then the rail is watched, not read once.**  Up to 60 s for it to fall into
the band and stay there 2 s with the line off (`BACKUP_SETTLE_MS`,
`BACKUP_CONFIRM_MS`).  The watch gives up early if the line comes back on (a
key, or a crank ending) or the rail holds steady above the band, falling less
than 20 mV in a second, which is a car still connected.  A pulse that was
not a cut but lasted 200 ms or more is reported as a short key cycle, as
before; a shorter one is ignored.
- **Every ignition wake that is not a key is logged**, with the pulse length
and the rail: "wake: ignition pulse, on for 482 ms, rail 11.35V".
- **The rail is also polled while asleep.**  With `APP_BACKUP_SUPPLY`, every
sleep-loop pass takes one INA conversion (`battery_poll_voltage()`, about
5 ms) at the tilt poll's 30 s, so no extra wakes (`BACKUP_RAIL_POLL_S` sets
the cadence if tow detection is off).  In the band, confirmed 2 s later, it
reports the cut once.  Back above it, it reports the car supply's return
once, past the battery gates, so `car power restored` goes out straight
away.  On the bench a cut was reported 37 s after the supply went off
without the pulse, and 8.3 s after with it; a return 20 s after the supply
came back.
- **A report owed on a cut or a return survives the pass.**  It was a
per-pass flag, and a movement check that ended the pass early (a cut that
also jolts the car) dropped it.
- The `APP_BACKUP_SUPPLY` help said the module runs from an LTO pack; it is a
CR123A cell.

### Quiet sleep passes stay quiet with the modem in PSM
`sleep_modem_release()` counted a registered modem as one to release, and in
PSM the modem is registered for good.  So every 30 s tilt poll woke the
console and called `modem_sleep()`, which only logged "sleep: modem left
registered": about 9 ms of UART and HF clock per pass, as much as the pass's
own work.  A pass that raised nothing now leaves alone a modem that says it
is asleep in PSM (`modem_psm_asleep()`).  One that is registered but awake —
just used, back on the network by itself, or not getting into PSM — is still
released as before.  Not yet seen on a cell that grants PSM: the bench's
refused it for the whole test.

### Alerts are held until answered
On 2026-09-30 at 19:55:19 the bench's `backup power: 9.19V` went out two
seconds before the network rejected the registration (EMM cause 9, TAC
12296), and the server never saw it.  The record sent with it was held and
arrived three minutes later; the alert, forgotten the moment the modem took
it, did not.
- **Alerts are held like records.**  Each keeps its slot until the reply to
the datagram that carried it comes in (`databuf_ack()` credits alerts too).
Unanswered after `APP_ACK_TIMEOUT_S`, or when the socket is about to close
(`databuf_settle()`, which now waits for alert replies as well), an alert is
sent again with the next send.  The queue is 8 alerts, up from 5.
- **An alert lost with the network is owed like a report.**  The sleep loop
keeps the modem searching and sends it as the network returns, rather than
an hour later with the next timed report.  One unanswered with the network
still up waits for the next send, so a server that is not answering is not
asked again every 30 s.  With timed reports off, an owed alert goes on its
own.
- **An alert sent on its own waits for its reply**, up to 4 s
(`RESPONSE_TIMEOUT_MS`), since the radio goes down straight after.
- **`aid=<n>`**: each alert line now ends `,aid=<n>`, consecutive within a
boot from a random start like `rid=`, and the server drops a copy rather
than notify twice.  Traccar builds are unchanged: they hold nothing and send
no id.
- **Needs the server's alert dedup.**  A server without it shows the
`,aid=<n>` in the alert text and relays a resent copy twice.  Both the
l0destar server (`server/`, with tests) and the car's deployment have it.
It remembers ids in memory, so a copy that arrives across a server restart
is relayed again.
- Not yet proven on hardware: the bench test with `APP_DEBUG_DROP_DATAGRAMS`
was cut short when the module came off the bench.

## 0.4.63

### A datagram the modem accepted is not taken as delivered
Both drives on 2026-09-27 lost records the firmware had counted as sent.
Where tracking area 4096 meets 12296 (Morden/Mitcham) the network rejects
the tracking-area update with EMM cause 9, "UE identity cannot be derived",
and the modem drops its registration, attaches again and discards whatever
it had queued.  The device log has 16 such rejects at that boundary since
2026-09-11, on nearly every crossing and on Vodafone as well as O2, so it is
the network's and not ours.  At 10:57 it took a batch of three (rid
30531-30533).  At 11:50, pulling up at home, it took the last position and
the ignition-off record (30662-30663): the send that carried them had waited
for its reply, got none, and still counted.  Apart from that boundary, about
1% of driving records vanish with no network event at all (17 datagrams on
2026-09-26).  `transport_send()` returning 0 only ever meant the modem had
the datagram.
- **The reply is the receipt.**  The server answers every datagram, bound
to the request's nonce, so a reply identifies exactly the send it answers.
Each send now gets an id, the transport keeps the last eight nonces, and a
reply is credited to its send however late it turns up.  The socket is
kept between sends instead of closed after each one, so the replies have
somewhere to land.  That costs the radio nothing: the reply was always
transmitted, and was thrown away with the socket.  The release hint is now
`RAI_ONE_RESP` on every send, since a reply is always wanted.
- **Records are held until answered for.**  `databuf.c` keeps each sent
datagram's records under its id (`APP_DATABUF_UNACKED_SLOTS`, 6).  Once the
reply is in they are dropped.  If it has not come within
`APP_ACK_TIMEOUT_S` (30 s) they go back into the backlog and are sent again,
and the server drops the copy of anything that did arrive (same rid, same fix
time).  With every slot waiting, the oldest makes room the same way.  The
log says so at WRN, "datagram #N unanswered after S s — K records back in
the backlog", so the device log shows every datagram that went missing.
- **The backlog waits for proof the link works.**  It is flushed only once
something sent since the previous record — or since the network came back —
has been answered.  At 11:48 the modem sat on seven datagrams for 38 s on a
weak cell and delivered them in one burst, and the one after them never
arrived.  Resent records now wait for the link to come back instead of
joining the pile; the live record still goes each cycle, as before.
- **Before sleep, what is owed goes.**  Going to sleep, and at the end of
each timed wake, the device waits up to 4 s for the replies still owed
(`databuf_settle`), then sends the backlog while the radio is up, a couple
of datagrams at a time for as long as they are answered (`databuf_deliver`).
The ignition-off record's reply is collected rather than closed on, and a
backlog no longer waits an hour for the next wake.
- **Every reply is read, and so are its commands.**  Replies to sends that
were not waited for used to arrive at a closed socket.  The server deletes
a command once it has put it in a reply, so a command in one of those was
lost.  Each reply's settings and commands are now applied whichever send it
answers.  Several can arrive between two runs of the command parser, so they
merge: one-shot commands accumulate, and `fota=` and `track=` come from the
newest reply.
- Track mode's records are not held: they carry an IMU burst too big for the
backlog's slots, and a second copy of a one-second sample, a minute late, is
not worth the airtime.  The Traccar transport is unchanged: its HTTP 2xx
already is the receipt, and `APP_DATABUF_UNACKED_SLOTS` defaults to 0 there.
- **`APP_DEBUG_DROP_DATAGRAMS`** (bench only, default 0) reports every Nth
send as sent and discards it, which is how a lost datagram looks from here.
- **Needs the server's copy detection.**  A server without it stores a
resent record twice.  Both the l0destar server (`server/`, with tests) and
the car's deployment have it.

### A drive keeps recording without a network
`STATE_IDLE` parked the loop while there was no registration and recorded
nothing but ignition changes.  The backlog's "drive into the backlog" path
only ran if a send failed first, and a modem in the middle of a
tracking-area update accepts sends.  At 10:57 the receiver kept fixing
through the 16 s outage and a single record was built.
- **With the key on, recording carries on into the backlog.**  `send_data()`
puts the records straight into it rather than hand them to a modem with no
registration, which would take them and then lose them with its bearer.
The first send after the network returns leads, and the backlog follows
once that send is answered.
- **The radio's retry timer runs from `STATE_SEND` too**, since a drive
recording through an outage cycles between collecting and sending without
passing the idle poll.  It is reset whenever a send finds the modem
registered, so a later outage is not measured from an earlier one.
- The ignition-on fault-code read and the update check wait for a
registration.  The read goes out as its own datagram at once and would be
lost, and an update cannot download without one.

### A late record says when it was built
The server filed every record at the moment it arrived.  So a record sent
late, from the backlog after an outage or again after an unanswered send,
landed in the track and the journey after records built later than it.  A
late ignition-on record behind an ignition-off one was worse: the server
saw an ignition-on and would have raised the ignition alert for a drive that
had already ended.
- **`age=<s>`**: a record sent 10 s or more after it was built carries its
age, worked out afresh at each send from its own `up=`.
- **The server files it at arrival time less age**, and when something
built later is already stored treats it as history.  History fills in the
track but raises no ignition alert, opens or closes no journey, and changes
no settings or track mode.  The packaged server sums journey miles in time
order, so a resent record adds no detour.  A late record that is still the
newest, such as an ignition-off recorded during an outage, is the latest
state and acts like one, at the time it happened.

### The report owed after an outage goes when the network returns
A drive that ends without a registration leaves a report owed, sent once the
modem registers.  The sleep loop only looked every `RESEND_POLL_S` (30 s),
and an accelerometer wake that came to nothing skipped the look altogether.
On 2026-09-27 the modem was registered again at 11:50:54 and the report went
at 11:51:32.  The LTE handler now ends the sleep wait as registration lands
(`modem_on_registered()`), and a pass that finds the report owed on a
registration already there goes straight to it.

## 0.4.62

### PSM sleep engages
The car has run `CONFIG_APP_PSM_SLEEP=y` since 0.4.58.  When the network
grants PSM, sleep leaves the modem registered instead of taking it to CFUN=0:
the modem falls into PSM on its own once the active timer runs down, and the
next wake resumes instead of attaching again.  A modem that stays registered
without ever reaching PSM would draw milliamps, so the sleep loop checks for
that and falls back to CFUN=0.  On the car the fallback fired on every parked
wake from 0.4.58 to 0.4.61 — "PSM granted but the modem is still awake 70s
on", about 90 s after each send — so every wake still paid the full attach
PSM exists to avoid, on top of the tail PSM adds.
- **The modem's sleep notifications are compiled in.**  `APP_PSM_SLEEP` now
selects `LTE_LC_MODEM_SLEEP_NOTIFICATIONS`.  Without it the link controller
never subscribes to `%XMODEMSLEEP`, so `LTE_LC_EVT_MODEM_SLEEP_ENTER` never
arrived and the check could not see a modem that had gone to sleep.  The
modem was very probably in PSM for most of those 90 s — on the bench, on the
car's home cell, it gets there 12 s after the reply — and the fallback then
woke it only to power it off.  The notification threshold comes down from
the stock 20 minutes to 60 s
(`LTE_LC_MODEM_SLEEP_NOTIFICATIONS_THRESHOLD_MS`).
- **The check measures from the radio's last activity.**  It used to arm a
deadline on one pass and judge it about 90 s later.  When that deadline fell
due on the pass of a timed report, the send had just woken the modem out of
PSM, so it read as awake and was powered off — one wake in four.  On the
bench, with 150 s wakes, it fired on the fourth wake as predicted from the
log, and the wake after it attached again (3.9 s, 3.3 s of it attaching).
modem.c now records the radio's last sign of life — a registration, an RRC
change or a wake from PSM — and the loop falls back only when the modem is
not in PSM and the radio has been quiet for the active time plus
`APP_PSM_SLEEP_GRACE_S`.  Six bench wakes, no false fallback.  The warning
now reads "still awake 70s after its last radio activity".
- **A wake from PSM takes about a second.**  On the bench, on the car's home
cell (O2 234-10), a timed wake that resumes from PSM was awake 0.92 to 1.35 s
with no attach, against 3 to 4 s when it attaches (0.4.61 on the car: median
3.0 s, 2.6 s of it attaching).  The modem enters PSM about 12 s after the
reply: the network releases the connection about 2 s after the last data,
then the 10 s active timer runs.  `wake_ms` ends when the modem is left to
fall asleep, so a PSM wake's figure leaves that tail out.
- **No RAI on this network.**  `%RAI` reports neither AS nor CP RAI on O2's
cells here, so the `SO_RAI` hints transport.c gives are ignored and the
connection stays up until the network's inactivity timer releases it.

### A wake from PSM still reports the signal
- **The reading is taken after the send.**  A wake that finds the modem in
PSM builds its record before the radio is up, and `%XMONITOR` has no
measurement to give from a sleeping modem, so on the bench every PSM wake's
record went out without `rsrp`/`snr`/`band`.  When a record goes out without
a reading, the wake now reads `%XMONITOR` once the reply is in, while the
connection that carried it is still up.
- **It travels as `ws=<rid>:<rsrp>:<snr>:<band>`,** beside `wt=` on the next
record, and like `wt=` it describes the record it names.  The server files
it there only where that record has no reading of its own, and never holds
it the way it holds a wake figure: the reading follows a send the server
answered, so the record is already stored.  No schema change; a server
without the change ignores the field.  On a Traccar build it rides as
`wakeRssi`/`wakeSnr`/`wakeBand` attributes, joined on the same
`wakeRecordId`.

### A part that does not answer at boot raises an alert
- **An INA228 or accelerometer that does not answer on I2C is alerted, not
just logged.**  The warnings reached the captured log, but they are silent
losses of what the device is for: with no accelerometer there is no
movement, impact or tow detection, and with no INA228 there is no battery
voltage, which the low-battery alert, the sleep safety gate and the
engine-running fallback all read.  The unit carries on reporting position as
though it were whole.  Seen on a new bench build on 2026-09-24, where the
INA228 did not ACK while the accelerometer on the same bus was fine.  Queued
to ride out with the first record, once per boot, so a board with a dead
part reports again after every restart, FOTA reboots included.
- **`CONFIG_APP_HW_FAULT_PRIORITY` (default 1)** sits above the 0 used for
settings changes and below the movement alarm's 2: a dead sensor needs
noticing, not acknowledging at 3am.  -2 silences it, for a bench board
deliberately running without part of its hardware.

## 0.4.61

### Telling a weak location from a weak antenna
The car reports -108 to -112 dBm on band 20, from two separate eNBs within
4 dB of each other.  That is cell edge, and O2 carries LTE-M on band 20 only,
so there is no better band being missed.  What a single reading from a single
parked spot cannot say is whether that is the location or the hardware.
- **Signal is sampled on its own cadence (`APP_SIGNAL_SAMPLE_S`, 60 s)**
rather than riding the cell group.  One reading per wake describes the
parking space and nothing else; separating a weak location from a weak
antenna needs readings from many places, because coverage swings tens of dB
along a route while a detuned or badly-fed antenna is close to the same
offset everywhere.  A drive now surveys the route.  `AT%XMONITOR` is free on
the radio — it reads measurements the modem already keeps for cell
reselection — so this costs an AT round trip a minute and about 23 bytes on
the records that carry it.  Skipped in track mode, which avoids AT commands
by design.
- **`CONFIG_APP_CONN_EVAL` (default n) adds path loss, RSRQ, CE level and TX
repetitions.**  `dl_pathloss` is the one that travels: RSRP says how strong
the signal arrived, path loss says how much was lost getting here,
normalised against what the cell says it transmits — so unlike RSRP it is
comparable across cells and distances, and excess attenuation in the antenna
path shows up in it directly.  `ce_level` above 0 says LTE-M is using
repetitions.  Off by default because unlike `%XMONITOR` it runs an
evaluation and is refused while the radio is busy, which on a drive with
GNSS running is much of the time; a refusal is not an error and the
`%XMONITOR` figures still go out.
- **`CONFIG_APP_NCELLMEAS` (default n) reports what else the modem can
hear.**  Camped on -111 dBm while a neighbour reads -95 is a selection
problem wearing an antenna problem's clothes.  The count matters too: a weak
antenna pulls the serving cell and its neighbours down together, so levels
alone cannot separate it from a bad location, but marginal neighbours fall
below the detection floor and the list thins.  The scan is asynchronous, so
the wake waits for it rather than powering the modem off underneath it.
- New columns `pathloss`, `rsrq`, `ce_level`, `tx_rep`
(`sql/2026-09-23_log_conn_eval.sql`).  None are carried forward: they are
measurements of a moment, and NULL means no evaluation ran.

### A wake stops paying for a second it did not need
- **Registration is signalled, not polled.**  `wait_for_registration()` slept
a whole second before its first look and stepped in seconds after that, so
every wake paid at least 1 s however fast the modem actually was — a quarter
of a 4 s wake.  It now waits on a semaphore the LTE event handler gives the
moment registration arrives, and checks the status once before blocking in
case the URC beat it there.  The slices left in the loop only feed the
watchdog; a registration inside one ends the wait immediately.

### PLMN selection optimization is back on
- **`CONFIG_LTE_PLMN_SELECTION_OPTIMIZATION=y`** (NCS defaults it on; this
build had turned it off).  Its help calls it faster "especially for
stationary devices", which is what a parked car is, and the attach is where
a wake's time goes.  It had been disabled so the modem would re-evaluate
operators each connection rather than stick with the last one — a fix for EE
on B3 winning selection over O2/Vodafone on B20, which locking the band list
to 8 and 20 has since settled on its own.  `attach_ms` now measures the
difference directly, so this is falsifiable rather than a hunch.

### A diagnostic for whether PSM is worth adopting
- **`CONFIG_APP_PSM_PROBE` (default n) asks the network for PSM and reports
the answer.**  The modem is at CFUN=0 for the whole sleep with PSM disabled,
so every wake re-attaches from scratch; PSM would make a wake an RRC resume
while drawing what an off modem draws.  Whether that is available cannot be
read off a modem that has never asked — `AT%XMONITOR` reports the
network-provided Active-Time, but a UE that does not request PSM is never
assigned one, so the field is empty either way.  The probe requests PSM
before CFUN=1 and logs `LTE_LC_EVT_PSM_UPDATE` at WRN, so on an
`APP_DEBUG_LOG` build the answer reaches the server's device log without
needing a console: "granted" with the timers, or "refused" when the network
returns an active time of −1.  Repeats are demoted to INF.
- **It observes without adopting.**  Sleep still ends at CFUN=0, which
detaches long before the requested active time could expire, so PSM never
engages and neither sleep current nor wake behaviour moves; the request only
adds a few IEs to the attach.  The requested active time (60 s) is
deliberately clear of both the timed wake, which powers the modem off within
a second or two of its send, and the 30 s ignition-sleep cadence.  Safe to
enable on a deployed vehicle, which is the point — it is the one place the
question can currently be asked.

### A slow wake says why it was slow
Six wakes on 2026-09-23 ran 3.9 s to 44.6 s on one cell, same RAT, no GPS
involved.  The records themselves showed the send was not the problem — 0.51
to 0.72 s from the device building a record to the server storing it, on the
fast wakes and the slow ones alike — so all of the variance is before the
record exists.  That is the LTE attach, which every wake pays in full: the
modem is at CFUN=0 for the whole sleep and PSM and eDRX are disabled, so
there is no registration to resume.  Neither of these changes that; they make
it measurable.
- **`wt=` gained a third part: how much of the wake was the attach.**
`wt=<rid>:<total_ms>:<attach_ms>`, stored in the new `attach_ms` column
alongside `wake_ms`.  Timed from the CFUN=1 that started the search to the
registration event that ended it, not from `wait_for_registration()`'s return
— that polls at 1 Hz and sleeps a second before its first look, so every
attach read as at least 1 s and was rounded to the second.  The event handler
runs on the URC, so this is the modem's own timing.  0 means the modem was
already registered and the wake paid no attach.
- **Records carry the serving cell's signal quality.**  One `AT%XMONITOR`
after each attach yields `rsrp=` (dBm), `snr=` (dB) and `band=`, converted
from the 3GPP indices on the device since that mapping is fixed by the spec.
The command is free on the radio — it reads measurements the modem already
keeps for cell reselection, with no over-the-air transaction — and costs one
round trip per wake, not one per record.  The figures ride the existing cell
group, but only while the reading is that record's own: the group also goes
out on a cell change and on a record built from a stored position, and on
those there is no fresh reading, so an old one is dropped rather than sent as
if it were taken now (`SIGNAL_FRESH_MS`, and the cell-change event drops the
reading it invalidates).  Never carried forward by the server either, unlike
the cell identity: signal moves continuously, and a copied value would read
as a measurement that was never taken.  This is what
makes the obvious hypothesis testable — LTE-M raises its repetition count as
coverage worsens, so the same procedure on the same cell takes several times
longer at a lower RSRP.
- Schema: `sql/2026-09-23_log_attach_signal.sql`.  On a Traccar build the
attach rides as a `wakeAttachMs` attribute and the signal as `rssi`/`snr`/
`band`.

## 0.4.55

### A quiet tilt poll no longer wakes the console
- **The parked sleep loop leaves the console suspended when a pass has
nothing to do.**  With tow detection on (`APP_TOW_TILT_DEG`, default 6) the
sleep wait is capped at `APP_TOW_POLL_S`, so a parked unit wakes every 30 s
for the tilt check, and every one of those passes resumed the console UARTE
first.  An enabled UARTE holds the HF clock, so each poll showed on the input
current as a brief ~100 µA hump over the ~35 µA sleep floor, spent on a pass
that reads the accelerometer twice, reads the ignition pin and logs nothing.
A pass is now quiet when the wait timed out, no ignition or accelerometer
interrupt is latched, no resend is owed and no timed report is due; a quiet
pass runs with the console suspended, and skips the log drain and 2 ms settle
before the next wait.  Every branch a quiet pass can still turn into — tilt
over the threshold, the tow re-arm, the orientation tamper check, a polled
ignition change, the accelerometer's INT1 still high, the modem
power-off, the wake-cost line and key-on — resumes the console first,
so nothing it logs is lost.  The bit-banged accelerometer reads still run the
CPU for about 2 ms per poll, so the hump shrinks rather than disappears.  Not
yet measured on hardware.

## 0.4.54

### Every engine-off wake reports what it cost
- **`wt=<rid>:<ms>` carries a wake's duration and names the record it sent.**
Engine-off telemetry is where a parked unit spends its power — each wake pays
for a modem bring-up, a registration, a fix and a send, and one that cannot
register pays the whole `APP_NETWORK_SEARCH_TIMEOUT` before giving up — and
none of that was visible afterwards: the stored row said what was sent, never
what it took to send it.  The sleep loop now times from the wake to going
back to sleep with the modem off, spanning the `RESEND_POLL_S` passes of a
report that had to wait for registration, since that is exactly where a bad
wake's power goes.  The server files it against the record named, in the new
`wake_ms` column.
- **The figure lags at least one record by necessity.**  A wake cannot measure
itself: the device is still awake when it builds the record, and on a bad
wake most of the time comes after that record exists.  So it is finished once
the wake is over, held in `wake_pending`, and emitted on the next record of
any kind.
- **Every record now carries `rid=`, the device's own id for it.**
Consecutive within a boot, so a gap in it is a record that never arrived, and
seeded at random at each boot, so no two boots reuse the same ids.  It is
what lets the wake figure name its record instead of meaning "the one
before" — which is the wrong row in exactly the case the figure is most worth
having.  A wake whose own send failed leaves its record in the backlog, and
the backlog is flushed *behind* the live record that describes it; the server
holds the figure on the `device` row until that record lands.
- A wake that built no record at all has nothing to attribute the figure to,
so it is logged and dropped rather than filed against an unrelated record; a
wake that skipped its send on the battery gate is not measured at all.  On a
Traccar build the pair goes out as `wakeRecordId` and `wakeMs` attributes of
the record carrying them, since Traccar cannot amend a stored position.
- Schema: `sql/2026-09-22_log_wake_ms.sql` and `sql/2026-09-22_log_rec_id.sql`
(`migrations/` in the packaged server).  Not to be confused with the existing
`waketime` column, which despite its name holds seconds of uptime.

### A parked unit that cannot reach the network stops looking
- **`CONFIG_APP_NETWORK_SEARCH_TIMEOUT` (default 300 s, 0 = no limit) bounds
the search.**  With the ignition off, the radio is left looking for a network
for this long — counted from the moment it is brought up, so the 60 s
`APP_NETWORK_REGISTRATION_TIMEOUT` is part of it — and then powered off until
the next timed report.  Nothing else keeps a parked unit awake, so this is
what bounds the power it spends somewhere the network cannot be reached.
Before, a timed wake that missed registration left the modem searching until
the next wake, up to an hour (it was left up on purpose so the record could
go out when registration arrived, and now still is, for the length of the
window), and a boot with the key off idled in the main loop with GNSS and the
modem both searching until the network came, however long that took.  A key
that has been turned off again on a wake or a boot that never registered,
and a drive that lost the network and then parked, waited the same way; they
give up at the same point.  Anything recorded while waiting goes to the
backlog for the next send that gets through.  The search is not limited with
the ignition on: the car is running, and the drive should be reported as
soon as coverage returns.
- **No fix is attempted without a network to send it over.**  A timed wake
that could not register ran the receiver anyway when a fix was due — up to
the cold-start timeout, five minutes — for a record that could only go to the
backlog.  The search is left to the next wake that has a network: the no-fix
backoff (1st, 2nd, 4th, 8th, 16th wake, then every 16th) now counts only
wakes with a network, so the first of them searches, and a movement fix stays
wanted until then.  The same at boot: with no network and the key off the
receiver is not started, and the unit goes to sleep with the modem searching
for what is left of the window; the sleep loop sends the first record, and
runs the power-on update check, if the modem registers in time.
- **A wake with no stored position now polls for the registration it needs.**
The report was only marked as owed when a record had been built and its send
had failed, so a unit with no position since boot — which builds no record —
left the modem searching with nothing watching for the registration that
would have let it search for a fix.  The report is owed whenever the wake
ends unregistered.
- **The wake interval backs off while there is no network.**
`ENGINE_OFF_BOOT_INTERVAL` — the cadence from boot until the first server
reply sets one — is an hour rather than 900 s, and each consecutive timed
wake that cannot register doubles the wait until the next, up to
`CONFIG_APP_NO_SIGNAL_MAX_INTERVAL` (default 86400 s, 0 = no backoff): 1, 2,
4, 8 and 16 hours, then a day.  A unit somewhere with no coverage at all —
an underground car park, a container, a shipped spare — was waking on its
full cadence to spend a bring-up and a search window on a send that could
not happen.  The first registration puts it straight back to the configured
interval, and so does confirmed movement, since the likeliest reason
coverage returns is that the vehicle has been moved into it.  The server's
interval is never overwritten: the backoff is local, and by the time a
record reaches the server it has already been cleared, so the `int=` the
device reports stays the one it was given.
- **Key-off during an outage no longer floods the backlog.**  With the last
send failed and the ignition off, the send state went round again to report
the change — once a second, for the whole outage, each pass pushing another
copy of the ignition-off record into the backlog and thinning the drive's own
records out of it.  It now hands over to the idle state, which records the
change once, holds it for the send that follows registration, and gives up at
the timeout above.

## 0.4.51

### A stale reply no longer costs a warning
- **A tag that fails to verify is logged at debug, not warning.**  The
response AAD binds a reply to the nonce of the request it answers, so a reply
the server sent to an earlier datagram fails the tag check by construction,
and `transport.c` already treats that as a stale reply: it skips it and
listens on for the one it wants, warning only if nothing valid arrives by the
deadline.  But `crypto_decrypt()` warned on every failed check of its own, so
each skipped reply still sent `psa_aead_decrypt: -149` to the server — 60 on
the car, 42 of them within seconds of a registration outage ending, when the
replies to the sends made during the outage arrive together.  An
invalid-signature status is now debug-only; any other status, a key or buffer
problem, is still a warning, and the transport's own `response decrypt
failed` still fires when no reply authenticates.

## 0.4.50

### An hour of sleep is no longer logged as an outage
- **A deliberate modem power-off is not a lost registration.**  The car's
device log carried a pair of warnings for every timed wake on 2026-09-20:
`registered again after 3628 s (status 5)` as the modem came up, and a second
later `registration lost (status 0) — waiting for the modem` as it went back
down.  Both were the firmware's own doing.  A timed wake brings the modem up
with CFUN=1, sends the record and powers it off again with CFUN=0; the modem
answers that with a not-registered URC, and the LTE event handler — which
logs a loss at WRN so a real outage and its length reach the captured log —
could not tell it from the network going away.  The 3628 s was the 3600 s
loop interval plus the bring-up: every hour of sleep read as an hour without
a network, and a real hour-long outage would have looked the same.
`modem_power_off()` clears the handler's state before CFUN=0, so the URC is
logged as the plain status change it is and the next registration has
nothing to be measured against; sleep entry, the end of a timed wake, the
parked-impact branch and the pre-reboot power-off in the update path all go
through it.  A genuine outage still open when the modem is powered off gets
its closing line, `powering off still unregistered, N s after losing the
network`, so the log never shows a loss without an end.  Verified on the
bench: sleep entry now logs `nw reg status: 0` at INF and nothing at WRN.

## 0.4.49

### Threshold alerts on OBD telemetry
- **`CONFIG_APP_OBD_ALERTS` queues an alert when a PID crosses a line.**
A comma-separated rule list, `"coolant>=90,rpm>6500,stft<-12.5/2"`, judged
on the live snapshot after every poll (`src/obd_alert.c`), so a slow PID is
checked as soon as its rotation slot reads it rather than when the next
record is built.  One alert per crossing, at `APP_OBD_ALERT_PRIORITY`
(default 1), worded `coolant 92C (>= 90C)`; a clear at priority 0 once the
value is back across the threshold by the hysteresis, a twentieth of the
threshold unless the rule gives one.  Rules re-arm at key-off, not on a
mid-drive reopen.  A rule that does not parse disables the list with the
reason logged.  On a Traccar build a coolant or intake alert is a
`temperature` alarm.  See KWIRE.md, "Threshold alerts".

### A cell change on the motorway no longer costs a minute of tracking
Two dropouts on 2026-09-19's long drive, at 10:43 and 11:00, each held the
track for a minute or two on a motorway with a clear sky.  Both were the
firmware making a routine LTE cell change worse; the captured log shows how.
- **The registration retry timer measures the current outage.**  When the
modem loses registration the idle poll starts a timer and, after
`APP_NETWORK_RETRY_INTERVAL` (300 s), brings the radio up again.  The timer
was cleared only by the poll seeing registration return, but the LTE event
handler flips `network_ready` back on its own after every blip, and the poll
is then skipped — so the timer kept the start of some earlier outage.  Every
later blip fired the bring-up at once: at 10:43:10 the modem reported status
4 while reselecting on the motorway, and 5 s later the log reads `no
registration for 300s — bringing the radio up again`; the same again at 11:20
(3 s) and on 2026-09-18 at 20:12 (21 s).  It now resets whenever the unit is
registered.
- **`modem_radio_up()` leaves a modem that is already up alone.**  The
bring-up reapplies the link settings and CFUN=1, which is what a modem
reinitialised after a fault needs (it comes back at CFUN=0).  Issued to a
modem that is already in normal mode it is not idempotent: `+CGDCONT` is
refused while attached (`CGDCONT: 65536` in the log), and `+COPS=0` makes the
modem start PLMN selection over even in automatic mode (Nordic's own advice
for leaving an unwanted network) — the likeliest reason the 10:43 blip became
63 s without a network, and a 30 s hole followed the 11:20 one (the EMM cause
9 rejects around that one were the network's, and happened before the
bring-up too).  The comparable blips left alone (09:19, 10:14) cost under
15 s.  It now reads `+CFUN?` first and does nothing when the modem is in
normal mode; a modem that is up but not registering is left to its own
periodic search.
- **A starved warm search says so.**  At 10:59:41 the receiver had a fix;
then none for the whole warm wait while the modem worked through a cell
change.  Whether LTE's idle-mode work was starving the receiver of windows or
an RRC connection was blocking it outright is not in the log, because a warm
wait recorded neither.  Priority mode is not the answer there: it takes the
radio from the very measurements the modem needs to finish a cell change, and
Nordic's note on the call is to time it away from anticipated data transfer,
which a drive never is.  So a warm wait now logs its starved epochs, and the
timeout line carries what the receiver saw (satellites, blocked or not), so
the next one can be read.
- **The fix wait is a deadline.**  It counted down its one-second semaphore
waits and ignored the OBD poll that runs between them, so the 60 s warm wait
above took 88 s.  It now runs to a `k_uptime_get()`-based deadline.
- **A receiver that fixed within the last half hour searches before it asks
nRF Cloud.**  The restart after a warm timeout makes the next collect a cold
one, and a cold collect with an assistance request outstanding fetched it up
front, pausing the receiver for the whole exchange.  At 11:01:11 that fetch
ran 21 s into a TLS connect timeout on the very link that had just failed,
before the search even began; the retry from the wait succeeded in 5 s.  With
a fix younger than `AGNSS_FIX_FRESH_MS` (30 min) the ephemerides are still
good, so such a collect searches first and only fetches from the wait after
`AGNSS_RETRY_INTERVAL_MS` (15 s) without a fix.  A receiver that has really
lost its data — boot, a long stop — still fetches first.

### Recovery brings the radio up the same way everywhere
- **`modem_recover()`'s CFUN cycle and library restart go through
`modem_radio_up()`.**  Both set the APN and CFUN=1 and nothing else, so a
modem that came back through either registered without `%REL14FEAT` and
`%RAI`, quietly costing the GNSS duty cycle — the gap `modem_rescan_plmn()`
already closes after its own CFUN=4.  Neither path ran on 2026-09-19.

## 0.4.48

### Telemetry can go to a Traccar server
- **`CONFIG_APP_TRACCAR=y` reports to Traccar instead of the l0destar
server.**  `src/traccar.c` is built in place of `src/transport.c` and sends
the same lines — records, alerts, fault-code reports — as OsmAnd-protocol
HTTP requests to `APP_TRACCAR_HOST` on its OsmAnd port (`APP_TRACCAR_PORT`,
5055), the device identified by its IMEI or `APP_TRACCAR_ID`, over TLS when
`APP_TRACCAR_SEC_TAG` names a CA.  The record builder, batching, the backlog
and the alert queue are untouched.  Record fields arrive under Traccar's own
attribute names where it has one (`power`, `ignition`, `sat`, `versionFw`,
`rpm`, `coolantTemp`, the fuel trims unscaled ...) and their own otherwise;
alerts become positions with `alarm=` set from the wording (movement, tow,
tampering, accident, powerCut ...).  Traccar's *custom* command is returned
in the response and goes through the same command parser as the l0destar
server's, so `int=`, `movealarm=`, `locate`, `fota` and `reboot` work from
there.  See `TRACCAR.md` for the mapping and what Traccar cannot do:
settings from the server, track mode, update adverts, the device log.
- **One TCP connection is kept across sends.**  Release assistance drops the
RRC connection after each response, and closing the connection after that
would need a fresh one just for the FIN, so `transport_close()` keeps the
socket and only hints the release; `transport_teardown()` drops it, which
now happens before every `lte_lc_power_off()` (a no-op for the UDP
transport, whose socket is already closed by then).  A request on a
connection the server has meanwhile dropped is retried once on a new one.
- **A 4xx answer drops the report, a 5xx keeps it.**  400 is Traccar not
knowing the identifier; holding such a report in the backlog would retry it
forever and escalate the modem recovery for a link that is fine.
- **A build with no update server skips the update check** instead of
failing DNS on an empty hostname at every power-on: `APP_FOTA_HOST` empty
and `APP_SERVER_HOST` empty, as a Traccar build has them.

## 0.4.47

### A short key cycle no longer leaves the unit idling awake
- **IDLE sleeps when the ignition is off and nothing is owed.**  Leaving
sleep on the ignition line needs it on for only 200 ms, but IDLE then spends
seconds in `modem_connect()` before it polls the line again; a key that was
off again by then left no transition to act on, and since sleep was only
entered from the send state the unit sat polling with GNSS running until the
next timed record (or the next key).  Seen on the bench on 2026-09-16 with a
quick ignition pulse: awake and silent for minutes until the ignition was
poked again.  The same idle followed a routine collection that found no fix.
- **A key cycle that is over by then still reports once**, from the cached
position, before sleeping — so poking the ignition to get an update works
whatever the pulse length instead of needing the key held for a second or
two.

### A tracker on the inline battery backup keeps reporting
- **`CONFIG_APP_BACKUP_SUPPLY` (default `n`) declares the backup module.**
The module holds the rail at about 9 V while car power is absent, which is
under both timed-report gates (`APP_BATTERY_POWEROFF_MV` 11.8 V, after which
the next check is a day away, and `APP_SLEEP_SAFETY_MV` 12.0 V): a unit whose
power had just been cut would have gone silent for 24 hours, the opposite of
what the module is for.  With the option set, a reading between
`APP_BACKUP_MIN_MV` (8.5 V) and `APP_BACKUP_MAX_MV` (9.7 V) with the ignition
off is backup power: the timed wake reports as normal and the two gates are
bypassed.  Off by default because without the module a car battery in that
band is flat.
- **`backup power: 9.05V` goes out at priority 1, `car power restored: 12.60V`
when the rail returns.**  A cut supply on a parked car is a tamper signal, so
it carries the movement alarm's priority rather than the low battery's.  The
same 60 s ignition-off settle guard as the low battery alert keeps a crank
sag out of it, and the low battery alert itself stays quiet in the band.
- **A power cut wakes a sleeping tracker.**  Nothing about a cut reaches a
sleeping unit on its own - the wake sources are the timer, the accelerometer
and ignition-present - so revision F of the module lifts the ignition line to
about 12 V for ~0.4 s as its boost starts.  The sleep loop now latches the
ignition interrupt rather than trusting the pin level (which is also why a
quick key cycle used to need a second or two to take), acts on a pulse that
landed while it was busy before the next wait, and on an ignition wake reads
the rail first: in the backup band it is the module's pulse, so
the unit reports at once (the `backup power` alert goes with that record,
without the settle wait) and goes back to sleep; anything else is the key-on
it always was.  Without the pulse a cut is still found at the next timed
wake.

## 0.4.46

### A timed report that misses registration goes out when the modem registers
- **The sleep loop sends it instead of powering the modem off.**  A timed
wake gives up on registration after `APP_NETWORK_REGISTRATION_TIMEOUT` (60 s)
and leaves the radio searching, and the record goes to the backlog.  When the
modem registered a minute or two later, the next pass of the sleep loop
powered it straight off, so the record waited for the next timed wake an hour
on.  Observed on 2026-09-14: the 07:57 wake gave up, the modem registered at
08:00:31 and was powered off at 08:00:57, and the record arrived at 08:59; the
same happened at 02:49 and 04:51.  A report that failed for want of
registration is now owed: the loop polls every `RESEND_POLL_S` (30 s) and, once
the modem registers, reruns the timed report — a fresh record, the backlog and
the server's reply — before powering the modem off.

### A parked unit's records no longer carry a phantom speed
- **A speed goes out only with the fix it came from.**  Every timed check-in
while parked reuses the stored position, and it used to repeat that fix's
speed too, for as long as the unit slept: on 2026-09-14 the car's hourly
records carried 0.68 mph from the fix taken after its 06:56 reboot, and the
page showed 1 mph.  A fix older than `SPEED_FIX_MAX_AGE_MS` (10 s) now goes out
with speed 0.
- **Every ignition-off record reads a residual GNSS speed as stopped.**  The
`IGN_OFF_STOPPED_KMH` cut (3.22 km/h, 2 mph) applied only to the record where
the key turned, so a fresh fix taken while parked, such as the one after a
reboot, still reported the receiver's standstill noise.  Above the threshold a
roll-away or a tow reports what it measured.

### Connect Kit builds from a fresh clone see satellites
- **The GNSS antenna settings are committed.**  The Connect Kit's GNSS
amplifier is powered from the nRF9151's COEX0 pin, which the modem only drives
once the modem antenna library has sent `AT%XCOEX0`.  NCS turns that library
on only for Nordic's own boards, and the settings lived in the gitignored
`makerdiary.conf`, so a fresh clone built Connect Kit firmware that could not
see a satellite.  They now live in
`boards/nrf9151_connectkit_nrf9151_ns.conf`, which every Connect Kit build
applies.

### Bench harnesses no longer reset themselves
- **The watchdog is armed only in tracker builds.**  Since 0.4.36 a missed
feed really resets the SoC, and the board test, provisioning mode, K-wire
discovery, the CAN and K-line tests, the accel, voltage and L-sense streams,
the CAN bench agent and the LTE power test all wait in loops that never feed
it, so each reset about 35-45 s in.

### A unit with no position sleeps instead of searching awake
- **With the ignition off and no fix since boot, it goes to sleep.**  A record
needs a position and sleep was only entered after a send, so a unit that
started where GNSS could not see the sky, such as an underground car park
after a key-off update, stayed awake with GNSS searching until a fix turned
up.  Its timed wakes now search for a first fix on the 1st, 2nd, 4th, 8th and
16th wake and then every 16th.

### An update no longer interrupts a drive or retries in a loop
- **No update starts while the engine is running.**  The main loop ran any
pending check on every pass, so a download usually began mid-drive: GNSS and
telemetry stopped for minutes, then the unit rebooted while driving.  It now
waits for the engine to stop; key-off and timed wakes still check, and a
manual `fota` command waits too.
- **A failed download backs off.**  It only bumped the failure count, so the
`fota=` in the next reply re-armed the check, within half a minute while
driving, stopping GNSS each time.  It now backs off like any failed check, 10
minutes doubling to 80; the `fota` command still overrides it.
- **One download budget per check.**  `APP_FOTA_DOWNLOAD_TIMEOUT_S` was meant
to bound a whole check, but each attempt started its own deadline, so one
check could keep GNSS stopped for about 40 minutes.  Every attempt now shares
the check's deadline.
- **The failure alert counts the attempts made.**  `fota: x -> y failed after
N attempts` always gave the configured number, even when the budget stopped
the check sooner.
- **A reverted update is reported once.**  The record of a staged update
survives a warm reset, and nothing marked its revert as reported, so every
later warm reset raised `failed to boot` again and sent the server another
`F,fota,failed` line.  Later boots now only restore the refusal of a version
that has used up its attempts.
- **An inhibited build says so.**  With `APP_FOTA_INHIBIT` the `fota` command
replied `fota: check queued` and cleared the record of a version that had
failed to boot, though no check would run.  It now replies `fota: updates
inhibited` and leaves the record alone.

### A late registration no longer leaves the IMEI unset
- **The IMEI is read before connecting.**  It was read only inside a
successful start-up connect, so a modem that registered after the 60 s
start-up wait left it unset for the whole boot: every send was dropped with
`IMEI not set`, and the power-on update check asked for `imei=unknown`.
`AT+CGSN` needs no network, so it is now read as soon as the modem library
starts.

### Command replies match what the unit does
- **`locatenow` and `tomtomnow` take a fresh fix while awake.**  The send path
stops GNSS before it runs the commands in a reply, so their record waited out
the 60 s fix timeout on a stopped receiver and reported the last known
position.  With the ignition on they now resume GNSS first.
- **A build without track mode ignores `track=`.**  `APP_TRACK_MODE=n`
compiles the mode out, but a `track=1` in a reply still set the flag and sent
`track mode ON`.

### The K-wire L line is driven only for a vehicle that needs it
- **Discovery tries K alone first.**  It drove the L line whenever
`APP_L_SEND_ENABLED` allowed, the default on v3.3 and v3.4, and its summary
said `L wire driven` whenever that setting was on, so it could not show
whether a vehicle needed L.  Each 5-baud init now goes out on K alone, and
again with L only if that gets no answer; the summary says `L wire needed`
only then and suggests `CONFIG_APP_KLINE_USE_L=y`.  A sweep that finds nothing
on K alone is repeated with L, which takes about as long again.
- **The runtime session can drive L.**  `kline_session_open()` always opened
on K alone, so a vehicle that needed L would pass discovery and then never
open a session.  With `APP_KLINE_USE_L` it drives L as well, after the same
short-to-battery test.

### The bench tools no longer leave a board drawing milliamps asleep
- **`reset.sh` does a pin reset.**  Its soft reset left the nRF9151 in debug
interface mode, drawing milliamps asleep until a pin reset or power cycle.
USB now re-enumerates on every reset, as it does after `flash.sh`.
- **`ifmcu/build.sh` refuses a clone without the whole fix.**  It builds only
a Makerdiary clone that contains PR #20's merge and has no local changes.  An
older version of the script patched the clone itself, which made a clone from
before #20 look fixed.

## 0.4.43

### A failed A-GNSS fetch no longer leaves a cold start unassisted
- **The in-search fetch is retried.**  When the receiver asks for assistance
and the fetch at the start of a cold search fails, `gnss_collect()` now
tries `AGNSS_RETRIES` (2) more times, `AGNSS_RETRY_INTERVAL_MS` (15 s) apart,
from inside the fix wait and only while the modem is registered; the
receiver keeps searching between attempts.  It used to make one attempt and
then wait out the search unassisted, with nothing asking again until the
next cold collect.  Observed on 2026-09-13: one fetch timed out at key-on
(-116, HTTP 0), the search took 2 min 23 s, and no telemetry went out
meanwhile.
- **GNSS priority mode is only requested when the receiver is starved.**
Every cold collect turned it on straight away and re-armed it every 30 s,
holding it for the whole search — over two minutes in that same cold
start, during which the modem dropped off the network.  It is now requested
only after `GNSS_PRIO_STARVED_EPOCHS` (5) consecutive epochs flagged
`NOT_ENOUGH_WINDOW_TIME` — Nordic's documented trigger, and the count its
location library uses — and not again while the modem's 40 s window may
still be running.  The first request in a search logs at WRN, so it reaches
the server's device log.

## 0.4.42

### A lost datagram no longer silences a parked unit
- **A reboot always leaves something to wake on.**  Settings live in RAM, so
every boot starts at the compiled `APP_ENGINE_OFF_LOOP_INTERVAL` — 0 on
these builds, meaning "never wake to report" — and only a server response
restores the real value.  One lost record was therefore enough to silence a
parked unit indefinitely.  Observed on 2026-09-12: the unit booted into
0.4.39 at 19:21:18, sent its post-boot record (the modem accepted the
datagram; the server never saw it, and logged no rejection), got no
response, and then had no telemetry timer for 90 minutes until the key
turned — uptime 5519 s on the next record, so it had neither rebooted nor
crashed.  `ENGINE_OFF_BOOT_INTERVAL` (900 s) is the cadence until the first
response, which then replaces it, including with 0.
- **`fw=` and `rst=` are cleared by the reply, not by the send.**
`s_fw_pending` was cleared as soon as `transport_send()` accepted the
datagram, so the once-per-boot diagnostics were discarded even when nothing
received them — precisely the case where the reset cause is worth having.
They now clear on a decodable response, the only proof the record arrived,
and ride the next record until then.  It is why the boot above is
unexplained: its `rst=` went out once and was lost.

## 0.4.39

### A waiting update installs at key off
- **`fota_check()` runs on the way into sleep**, so an update the server has
advertised is installed when the engine stops rather than at the next
telemetry wake.  The device already knew one was waiting — `fota=<version>`
rides every response, including the reply to the ignition-off record it has
just sent — but the key-off path reached `STATE_SLEEP` without passing any
of the three `fota_check()` call sites, so the pending flag sat there for
up to an hour.
- Key off is also the right moment for it: the radio is still registered
from that last record, the battery has just come off the alternator, and
the vehicle is not about to be driven.  The alternative was a download an
hour later on a colder battery, and only on a unit that still had an
engine-off interval to wake on.  A no-op when nothing is pending, so an
ordinary key off costs no traffic.

### The "updated to" notification comes from the server
- **The device no longer raises it; it only logs it.**  It could only ever
raise it on the one boot that writes the MCUboot confirm flag — every later
boot returns at `boot_is_img_confirmed()` — and on that boot it was an alert
queued in RAM that had to survive a working link and no reset before the
next send.  When it did not, nothing re-raised it, so an update that worked
perfectly could look silent and a missing notification meant nothing either
way.
- The server raises it instead, in `fw_check_running()`, when the version a
device reports in `fw=` matches the version it was told to stage.  That is
state rather than a one-shot event: it survives every reboot and arrives
with the first record that gets through.

### A failed update is remembered, reported, and not retried forever
- **The device knows whether its own update took.**  What it stages is
recorded in `__noinit` RAM, which survives the reboot that applies it, and
the next boot compares it against what is actually running: the same
version means success, anything else means MCUboot reverted it.  Until now
the device had no memory of having tried, so a bad image was downloaded
again on every wake — 300 KB an hour with the engine off, which is a
flattened car battery rather than a missed update.
- **A reverted version is blocked locally** after `FOTA_MAX_ATTEMPTS` (2),
and the block is version-scoped: the `fota=<ver>` advert that rides on every
response stops meaning anything for that version, so no manifest is fetched
either, while a newer version is still picked up automatically.
- **Two new lines tell the server what happened**: `F,fota,staged,<new>,
<old>` before the reboot, and `F,fota,failed,<staged>,<running>` from the
boot that finds itself running the old image.  Sent as their own datagrams
like the DTC report, queued until there is a link.
- **`status=blocked` in the manifest is understood** as the server
withholding an image from this device, with an optional `reason=`.  Logged
once, not retried, and scoped to that version.
- **The bare `fota` command is the manual retry**: it clears the local
block, the attempt record and the failure holdoff, so an operator can force
another go at a version the device has given up on.

## 0.4.37

### The tracker stopped tracking mid-journey on a car with charging control
- **The vehicle sheds its alternator on purpose, and that read as "engine
off".**  Once the battery is topped up this car's ECU cuts alternator output
to save drag, and two days of logs show the rail sitting at 12.2-12.5 V for
up to 140 s at a stretch — at any engine speed, including 2000-2500 rpm —
before climbing back to 14.3 V on overrun.  Parked, the same battery rests
at 12.0-13.1 V.  The driving-with-charge-cut band therefore overlaps the
engine-off band and is frequently *below* it, so no voltage threshold
separates the two.  `ENGINE_RUNNING_VOLTAGE` (13 V) was being crossed dozens
of times per drive and each crossing dropped the unit to its engine-off
cadence in the middle of a journey.
- **The debounce that was supposed to cover this was not in the path.**
`engine_is_running()` was a bare compare with no hysteresis at all, and the
`ENGINE_STOPPED_COUNT` counter lived only in `data.c`'s sampler — so
`main.c` demoted on a single sub-13 V reading and never consulted it.  Both
call sites now go through one function, which is the only place the voltage
verdict is formed.
- **Demotion needs corroboration, promotion does not.**  Nothing but an
alternator puts the rail above `ENGINE_RUNNING_VOLTAGE`, so voltage still
promotes on its own.  Going the other way now needs the rail low *and* the
vehicle standing still *and* both sustained for `ENGINE_STOPPED_HOLD_S`
(300 s); any GNSS speed above `ENGINE_MOVING_KMH` restarts the hold, so a
charge-cut episode cannot accumulate towards a stop however long it runs.
Key-on-engine-off while rolling — a tow, a coast — holds the running
cadence, which is the side to err on for a tracker.  Replaying both versions
over the logged drives: 39 false "engine stopped" calls mid-drive, now none.
- **Unchanged where the ECU answers.**  A fresh RPM figure still settles it
outright, so this only bites builds with no K wire, no session, or a reading
gone stale.  `ENGINE_STOPPED_COUNT` is replaced by `ENGINE_STOPPED_HOLD_S`,
`ENGINE_MOVING_KMH` and `ENGINE_FIX_MAX_AGE_S` — a wall-clock hold rather
than a sample count whose real duration depended on which state was polling.
- **The averaging in `battery_read_voltage()` was miscredited.**  Its
comments claimed it existed to suppress "~12 V readings mid-drive on a car
with no charging fault".  Those readings are real and no amount of averaging
removes them.  The eight-conversion average stays — it rejects alternator
ripple, worth a few tens of mV — and the comments now say so.

## 0.4.36

### A fatal error halted the unit instead of rebooting it
- **The firmware defines its own `k_sys_fatal_error_handler()`.**  Zephyr's
default calls `arch_system_halt()`, which locks interrupts and spins
forever, and `CONFIG_RESET_ON_FATAL_ERROR` (Nordic's opt-in reboot handler)
was not enabled.  So any fatal error anywhere — bus fault, failed assert,
stack overflow, a fault in any thread — killed the whole device: no
telemetry, no console, no ignition wake and no accelerometer alerts, because
interrupts were off, and nothing short of pulling power recovered it.  That
is the state a unit was found in after a drive on 2026-09-12, dead for hours
with the key having been cycled several times.
- **The handler leaves a note before rebooting.**  Reason, PC and LR go into
a `__noinit` struct that survives the warm reset, and dbglog folds them into
the `rst=` field of the next record that reaches the server:
`rst=sw+fatal:4@0x2a1c8` instead of a bare `rst=sw` that reads like a
commanded reboot.  Enough to place the fault in the map file.

### The watchdog is armed at the top of main(), not the end of bring-up
- **Arming it last caused a FOTA revert loop.**  The nRF watchdog cannot be
stopped once started and is not cleared by a soft reset, so after any
reboot — a FOTA swap, a fatal error — the previous image's watchdog is
still counting down its 12 s window while the new image boots.  With
`watchdog_init()` at the end of bring-up, behind the modem connect and the
A-GNSS fetch, the app did not take ownership until about eleven seconds in
and the watchdog fired first, at the same point every boot.  A swapped-in
image therefore never reached `fota_confirm_image()`, MCUboot reverted it,
the old image downloaded it again, and the unit spent 300 KB a cycle going
nowhere.  Armed at the top of `main()` the app takes ownership within a
couple of hundred milliseconds — task_wdt allocates the same hardware
channel, so the reload feeds the running watchdog — and every slow step in
bring-up already kicks as it waits.
- **The reset cause is logged at boot and cleared there.**  RESETREAS bits
are sticky until something reads them, and until now that only happened
when the first telemetry record was built.  A unit resetting during
bring-up never got that far, so the bits accumulated and a reading of
`sw+wdt` could not distinguish "rebooted, then watchdogged" from "one of
these happened three boots ago".  Reading it at boot makes each line the
cause of that one reset.  A unit already in a watchdog loop needs a pin
reset or a power cycle, which is what stops the watchdog.

### The watchdog was never armed
- **`task_wdt_init()` is given the hardware watchdog, and the timeout
callback lets it fire.**  Neither layer was active: Zephyr only configures
the hardware fallback when `task_wdt_init()` is passed a device, and this
passed NULL, so `CONFIG_TASK_WDT_HW_FALLBACK=y` did nothing; and task_wdt
only reboots by itself for a channel registered with no callback, so the
empty callback replaced that reboot with nothing.  A thread that stopped
feeding was therefore never noticed — which is how a unit that blocked
inside a modem call sat dead in a car for over an hour, ignoring the
ignition and the accelerometer, until it was power-cycled by hand.  The
callback deliberately does not call `sys_reboot()`: leaving the hardware
watchdog unfed resets the SoC a couple of seconds later and RESETREAS then
records a watchdog reset, so the next record carries `rst=wdt` rather than
the `rst=sw` of an ordinary commanded reboot.
- **`CONFIG_TASK_WDT_MIN_TIMEOUT` 100 ms -> 10 s.**  That symbol is how
often the background timer feeds the hardware watchdog, so with the fallback
finally armed it is also how often the CPU wakes during an engine-off sleep.
The default would have been ten wakes a second for the whole sleep; at 10 s
(the maximum the symbol allows) the cost is a rounding error against 134 uA.
- **The sleep wait is sliced.**  An engine-off sleep waits up to an hour in
one `k_sem_take`, far past the 32 s window, so it now waits in 20 s slices
and feeds between them.  A slice that expires does not take the semaphore,
so wake behaviour is unchanged.  Two operations that cannot be sliced — the
A-GNSS REST fetch and the modem's DNS lookup — are bracketed with kicks
instead, and the A-GNSS request timeout is 20 s rather than 30 s so that a
full timeout still fits inside the window.

### A modem crash recovers itself
- **`CONFIG_NRF_MODEM_LIB_ON_FAULT_RESET_MODEM=y`** replaces the
`DO_NOTHING` default.  A modem fault was logged and then ignored, and every
modem call returned `-NRF_ESHUTDOWN` from then on: the unit stayed awake,
fed and tracking GNSS, but mute.  Whether it ever came back depended on
`s_connected` still reading true at the moment of the crash — if it did,
`modem_recover()` reached its 30-minute restart branch eventually; if it
did not, the escalation timer never started and nothing recovered it short
of a reboot.  The library's reset thread now reinitialises within a second,
and unlike a reboot it keeps the databuf backlog.
- **`CONFIG_NRF_MODEM_LIB_FAULT_STRERROR=y`** so the fault line names the
reason (`NRF_MODEM_FAULT_BUS`) instead of printing a bare `0x4`.  It is an
ERR, so dbglog carries it to the server.
- **STATE_IDLE brings the radio back up.**  A reinitialised modem comes back
at CFUN=0 with no APN, no `%REL14FEAT` and no `%RAI`, and nothing awake put
those back — so the fix above on its own would have traded "mute until
reboot" for "mute until the next key cycle".  While unregistered, the idle
poll now calls `modem_radio_up()` (settings + CFUN=1, no wait) every
`APP_NETWORK_RETRY_INTERVAL`, which until now was defined and referenced by
nothing.  Not a blocking connect: the one-second poll stays in charge, so
the ignition line and the K-wire keep-alive keep being serviced.

### A late reply no longer costs the socket
- **A response that fails the tag check is skipped, not treated as the end
of the exchange.**  The response AAD binds a reply to the request nonce,
which is fresh random bytes per send, so a reply the server sent to an
earlier datagram cannot authenticate against the current one — by design.
Track mode already knew that and kept reading; the normal path did not, and
logged `psa_aead_decrypt: -149` / `response decrypt failed: -13` and closed
the socket instead, so the next send had to build a new RRC connection,
which made the next reply later still.  Both paths now read on until the
caller's deadline and report the skipped count with the fresh reply (INF) or
with the failure (WRN), which also distinguishes "the reply was late" from
"the only reply we got would not decrypt".  Nothing that fails to
authenticate is ever acted on; this only changes how long the socket
listens.
- **The response window is 4 s rather than 2 s** (`RESPONSE_TIMEOUT_MS`).
RAI releases the radio after each datagram, so a reply arrives after an
idle-to-connected transition and possibly a paging cycle, which two seconds
does not reliably cover on LTE-M.  Only paid when a reply is late or lost,
and only on the sends that ask for one.

### Modem recovery no longer blocks the whole firmware
- **`lte_lc_connect()` is gone from `modem_connect()` and
`modem_recover()`.**  It ends in a semaphore take of up to
`CONFIG_LTE_NETWORK_TIMEOUT` — 600 s by default, and this build never
overrode it.  Both escalation branches called it, so a unit that reached the
CFUN cycle or the modem restart in bad coverage stopped doing everything
else for up to ten minutes at a time: no ignition read, no accelerometer
service, no K-line keep-alive, no console output, and no watchdog kick.
From outside it was indistinguishable from a dead unit.
- Recovery now brings the radio up with `lte_lc_normal()` and returns.
STATE_IDLE already polls registration once a second while servicing
everything else, and records an ignition change that happens during the
outage, so waiting inside the recovery call bought nothing.
`modem_connect()` waits with the same polled helper `modem_rescan_plmn()`
uses, bounded by `APP_NETWORK_REGISTRATION_TIMEOUT` (60 s) and feeding the
watchdog each second, and leaves the radio searching when it gives up.

## 0.4.32

### Batch size is a build-time option
- **`CONFIG_APP_BATCH_SIZE` (default 3, range 1-16) replaces the hardcoded
`BATCH_SIZE` in `config.h`.**  Every other cadence and threshold in that
header already comes from Kconfig, so the one knob that decides how many
records ride in a datagram was the odd one out: changing it for a bench run
or a per-device build in `remote.conf` meant editing tracked source.  The
trade-off it sets is unchanged - a larger batch raises the record rate
(0.33/s at 1, ~0.6/s at 3) because each send costs an RRC connection and a
GNSS re-acquisition, at the price of the page updating every N records
instead of every cycle.  Values above three mostly hand the decision to
`BATCH_FLUSH_BYTES`, which flushes a datagram before it can overflow;
ignition changes, settings syncs and send failures still flush at once.

## 0.4.31

### Rail-fault alerts name the rail, not the domain
- **`RAIL:<net> fail` replaces `RAIL:<domain> rail fail`.**  K_EN switches two
rails (PP3V3_K and PP12V_K) and CAN_EN one, but the alert only carried the
domain name, so a K-line fault said `RAIL:K rail fail` with no way to tell
the 3.3V shifter supply from the 12V K output.  Each sense line now carries
its schematic net name, and the alert and the error log list the sense
line(s) that were not up when the timeout expired: `RAIL:PP12V_K fail`, or
`RAIL:PP3V3_K+PP12V_K fail` when both are down.  A domain with no named
senses still falls back to the domain name.

### Network mode is LTE-M only
- **`CONFIG_LTE_NETWORK_MODE_LTE_M_GPS` replaces
`CONFIG_LTE_NETWORK_MODE_LTE_M_NBIOT_GPS`.**  NB-IoT is no longer enabled in
`%XSYSTEMMODE`, so the modem will not fall back to it when LTE-M is
unreachable.  Registration has one RAT to scan instead of two; the cost is
that a site with no LTE-M coverage now has nothing to fall back to.  GNSS is
unaffected and stays enabled.
- **`CONFIG_LTE_MODE_PREFERENCE_LTE_M` dropped.**  Every
`CONFIG_LTE_MODE_PREFERENCE_*` symbol depends on one of the two dual-mode
network choices, so keeping it alongside a single-RAT mode is an unmet
dependency, and Zephyr's warnings-as-errors turns that into a failed build.
lte_link_control now sends preference 0 (auto), the value `%XSYSTEMMODE`
takes when one RAT is enabled.
- **Set in `remote.conf.example`'s `[common]` as well as `prj.conf`.**  A
per-device build layers only `[common]` and the IMEI section over `prj.conf`,
so that is where a fleet-wide RAT change belongs.

### Registration outages: visible, and the key-off record no longer waits
- The 16-minute silence on 2026-09-12 (08:51-09:07) was the modem losing
LTE-M and searching until it found NB-IoT.  Registration changes were logged
at INF, so the captured log showed nothing, and STATE_IDLE waits for
registration before it looks at anything else, so the ignition-off record
was built when the network came back rather than when the key turned: right
position, 15 minutes late.  Losing and regaining registration now logs at
WRN with the outage length, and the idle wait records an ignition change
straight away from the current fix (or last known position) and sends it
the moment registration returns instead of collecting it again.  The wait
also polls every second rather than every five, so the K-line keep-alive
stays inside P3max and the session is not dropped each time round.
- **"dbglog: N lines dropped" every datagram** was the deferred log core
overflowing its 1 KB buffer on every send (three ~300-byte record lines
logged back to back, and the log thread only wakes on a 1 s timer or ten
queued messages).  That count is global and level-blind, so the marker was
reporting lost console INF lines as if they were lost warnings.  The buffer
is now 4 KB with a wake threshold of 3, and dbglog keeps the core's count
apart from its own, reported as "console lines dropped (log buffer
overflow)".  Bench builds with `CONFIG_LOG_MODE_IMMEDIATE=y` warn that the
two settings have no effect; that is expected.

### IF MCU patch dropped - both fixes are upstream
- makerdiary/nrf9151-connectkit#20, the follow-up that routes every IF MCU
power-off path through the SEVONPEND-clearing helper, merged on 2026-09-10.
`ifmcu/patches/` is gone and `ifmcu/build.sh` builds the Makerdiary clone
unmodified; it now refuses a checkout that predates #20 rather than one that
merely predates #19. Neither PR is in a published Makerdiary release (v2.0.0
is from June 2026), so Connect Kits still need the IF MCU firmware built from
current `main` and flashed once by hand, as QUICKSTART.md describes. An
existing clone with the old patch applied needs `git checkout -- .` before
`git pull`.

### L-line sense streamer (bench)
- **`CONFIG_APP_L_SENSE_TEST`** (v3.3+ only) samples L_SENSE at 5 Hz from
boot and prints each reading in millivolts with its LOW/HIGH classification
against `CONFIG_APP_L_SENSE_LOW_MV`, marking transitions.  It opens by
asserting L_SEND for 2 s so the pulldown and the sense can be verified
against each other, then releases the FET and only observes the wire.
Loops forever like the accel and voltage streamers.
- **`CONFIG_APP_L_SENSE_LOW_MV` default raised from 1500 to 2800.**  The
SAADC pull-up ladder measures ~65K to VDD on v3.3, not the ~400K the sense
code assumed, so a grounded L wire reads ~2.0 V rather than 0.7-0.9 V and
the old threshold never classified it LOW.  A high, open or shorted line
still pins at the 3.6 V full scale; 2800 sits midway.  This also fixes
`kline_l_line_probe()`, which would have reported every healthy L wire as
shorted to battery.

### GPS rail fault no longer switches the bias tee off
- **A GPS rail that fails its rail-sense check at power-up now stays
enabled.**  `hw_domain_request()` used to treat every sensed rail the same:
if the sense line did not report the rail up within 50 ms it parked the
domain's pins and drove the enable low, which for the AUX/GPS domain meant
no antenna bias for the whole session.  That protection exists to stop the
nRF backfeeding a dead rail through a peripheral's clamp diodes, and on
v3.x no signal pin terminates in the GPS domain, so there is nothing to
protect.  A pin-less domain now keeps GPS_ENABLE high through the fault,
counts as on, and returns success; the `RAIL:AUX rail fail` alert and log
line are unchanged.  Domains with signal pins (CAN, K) behave as before.
- `hw_domain_faulted()` exposes the sticky fault, and the boot self-test
uses it to report the GPS rail without queueing a second alert.

## 0.4.26

### Faster telemetry while driving: one poll shape, records batched three to a datagram
- **The K-wire poll is the rotating one everywhere.**  RPM, speed, throttle
and load every call and one slow PID in turn, four or five exchanges instead
of thirteen, merged into a live snapshot; a slow value keeps its last
reading for up to 30 s.  The GNSS fix-wait tick now runs that poll (it
sampled RPM alone before), so the record built after the fix takes the
snapshot and normally costs no bus time; it polls itself only if the
snapshot is more than a second old.  The tick still never opens or reopens
a session.
- **`BATCH_SIZE` is 3.**  Each send costs an RRC connection and, because
GNSS and LTE share the antenna, a fix re-acquisition; with a record now
costing about a second, three per datagram roughly doubles the record rate
(~0.6/s from ~0.33/s) for a page update every five seconds or so.  Ignition
changes, settings syncs and send failures still flush at once.
- **The batch flushes against the datagram cap**, not the record buffer:
`BATCH_FLUSH_BYTES` leaves room for one more record plus log lines under
`UDP_PACKET_SIZE`.  The old threshold sat above what the transport can
send, which a larger batch would have hit as `-EMSGSIZE`.
- Track mode defaults move to a steady one record a second
(`APP_TRACK_PERIOD_MS` 1000) carrying the full 26 Hz IMU burst
(`APP_TRACK_IMU_SAMPLES` 24); 500 ms still works for two a second.

### Sleep-state power: wake interrupts moved off GPIOTE IN channels
- The two sleep wake sources (ignition sense and the accelerometer's INT1)
were edge-triggered, which on the nRF91 allocates a GPIOTE IN channel and
keeps the pin-detect logic clocked for the whole sleep, ~20-45 uA on the SiP
by Nordic's figures.  Both are now level-triggered (`GPIO_INT_LEVEL_LOW` on
the active-low ignition sense, `GPIO_INT_LEVEL_HIGH` on INT1), which routes
through the PORT/sense path and costs nothing while waiting.  Detection is
unchanged: sleep is only ever entered with the ignition off, so the one
transition that can matter is the sense pin going low, and INT1 is an
active-high pulse that idles low.  nrfx re-arms a level trigger after every
callback while the level persists, so both ISRs now disarm themselves and
the sleep loop re-arms the ignition wake before each wait (after the
semaphore reset, so a level already present is not swallowed).  The
awake-side impact trigger keeps its edge configuration.
- Measured on a v3.2 board across a 10K series resistor: sleep current down
from ~140.8 µA to 134 µA.

## 0.4.24 - track mode and minor bugfix

### Track mode (`APP_TRACK_MODE`, [TRACK_MODE.md](TRACK_MODE.md))
- **A server-side switch that turns the tracker into a live data logger.**
While it is on and the ignition is on, GNSS is stopped and a record goes
out every ~500 ms with the ECU's fast PIDs (RPM, speed, throttle, load every
cycle, the slow ones one per cycle in rotation, so the K wire sees four or
five exchanges a cycle rather than thirteen) and a burst of up to sixteen
IMU samples drained from the sensor's 26 Hz FIFO (`acc=`).  The transport
holds the socket and keeps the RRC connection up between sends
(`RAI_ONGOING`) instead of releasing the radio after each one.  Key-off
ends it with the usual final record; a switch-off from the server resumes
GNSS and the normal state machine.
- **The switch rides on every server response** as `track=<0|1>` beside
`fota=`, so a rebooted device converges on it.  The firmware acts only on a
change.  Records built in the mode carry `tm=1`.
- **The mode ends with the drive.**  The server clears the switch on the
ignition-off record, and after an hour of silence from a device that never
sent one; the firmware drops the mode on ignition-off and ignores a
`track=1` that arrives with the ignition off.  A switch left on by a page
that was never revisited no longer puts the next drive, or a device
rebooting after an update, into the mode.
- **Driving devices now read a server reply at least every
`APP_RESP_POLL_S` (30 s).**  Before, a send while moving never waited for
one, so a setting changed on the server did not reach the device until it
stopped.
- Server: `device.track_mode`, `log.track_mode`, `log.imu_burst`
(migration in `remote_tracker/sql/`), `/api/1.0/trackmode`, the live
stream sends every row and polls at 250 ms in the mode.  The tracking page
gains a **track** toggle and, while on, replaces the map with a dashboard:
RPM and redline, speed, throttle and load bars, a friction circle with a
learnt forward axis, a 60 s strip chart, and the slow values as tiles.

### No low-battery alert from a crank
- **The low-battery warning waits for the ignition to have been off for
`BATTERY_WARN_SETTLE_S` (60 s) and re-checks the line before alerting.**
Cranking pulls the rail to 9-10 V for a second or two, and the ignition
sense can read "off" for a moment inside that sag; the firmware then built
an ignition-off record at the bottom of it and raised "low battery: 9.8V"
on a healthy car.  A flat battery is still flat a minute later, so nothing
real is delayed by more than that.

## 0.4.22

### Warnings and errors reach the server (`src/dbglog.c`, `APP_DEBUG_LOG`)
- **Every WRN/ERR log line is kept in RAM and sent with the next telemetry
record that gets through.**  A deployed unit has no console, so until now a
stall in telemetry left nothing to read but the gap.  A second log backend
captures the lines (4 KB static: a 1 KB head that keeps the onset of an
incident and a 3 KB tail that keeps its most recent lines, evictions
counted), and `send_data()` appends as many as fit beside the record as
`L,<uptime_ms>,<E|W>,<module>: <text>` lines, at most
`APP_DEBUG_LOG_PER_RECORD` bytes per record.  They are freed only once the
datagram has left, so an outage's lines wait it out and arrive with the
first record after recovery.  Consecutive identical lines are collapsed into
one plus a "repeated N times" marker.  Nothing goes on the air while the log
is quiet.
- **The reset cause is reported on the first record after boot** as
`rst=<cause>` (`wdt`, `sw`, `pin`, `por`, `bor`, `lockup`, ...), read from
RESETREAS and then cleared so each boot reports only its own.  The server
already understood the field; the firmware never sent it.
- **Known-benign lines are not sent.**  `GNSS blocked by LTE` and the
A-GNSS `JWT needs modem time` wait were logged at WRN but are routine, and
now log at INF.  Lines the firmware does not own are excluded by a short
table in `dbglog.c` (module name plus message prefix): nrf_cloud's
once-a-second `Modem does not have valid date/time` during that wait, and
the modem's ERROR reply to `AT%REL14FEAT` on every boot.  The console still
shows all of them.
- Server: `L,` lines are appended on receipt to `/var/log/tracker/device.log`,
each stamped with the wall-clock time the device logged it (derived from the
`up=` field of the record they arrived with, or the receipt time marked
`(rx)` when there is none) plus the raw device uptime.
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

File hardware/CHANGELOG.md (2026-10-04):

# l0destar hardware changelog

Changes to the PCB designs over time, newest first. Boards no longer in the
tree are noted where they were removed.

## 04/10/2026

- Added battery backup v1.1 to address the problems found in v1.0

## 26/09/2026

- Swap INA228 for INA238, cheaper part with identical functionality for this
  use-case.

## 25/09/2026

- Removed the ESD diodes from the SMA connectors, these are unnecessary and
  detrimental to signal performance.

## 12/09/2026

- Swapped MAX33041EASA+ for TCAN3414DR in v3.4. Identical footprint/pinout
  but is fully rated for CAN-FD at 1/3 the price of the ADI chip.
- Cleaned up all unreferenced symbols and footprints

## 08/09/2026

- Fixed the ASM330LHHXTR accelerometer symbol in v3.4. Pins 10 and 11 are NC
  per the datasheet, but the symbol had them as hidden passive pins stacked on
  the GND pin, so the layout tied both pads to the ground pour on every board
  from v3.0 to v3.3. With those pins grounded the part never enters its
  low-power state, so it kept drawing current the whole time the board was
  asleep. In v3.4 pins 10 and 11 are proper no-connect pins and the pads are
  left unconnected.
- Tested on a v3.2 board by scraping pads 10 and 11 off the board under S8U1:
  sleep current dropped from ~140.8 µA to ~35.5 µA at 12V. v3.4 is expected
  to land slightly above that because of the LT8609 enable divider added in
  v3.3 (~9 µA), so roughly ~45 µA. The same rework applies to any existing
  v3.0-v3.3 board.

## 05/09/2026

- Renamed the OBD serial interface from "ISO-9141" to **K-wire** throughout the
  hardware tree. ISO-9141 was the wrong name for it: the K wire is a physical
  layer (ISO 14230-1) and ISO 9141-2 is only one of the protocols that runs
  over it, alongside KWP2000 (ISO 14230-4) and manufacturer-specific pre-OBD
  protocols such as VAG KW1281. This matches the firmware, which made the same
  correction.
- In v3.1, v3.2 and v3.3 this renames design data as well as prose:
  `iso-9141_interface.kicad_sch` -> `k-wire_interface.kicad_sch`, the sheet
  name to "K-wire interface", and the nets `ISO9141_K`/`ISO9141_L` (and
  `CAN_H_ISO9141_K`/`CAN_L_ISO9141_L`) to `KLINE_K`/`KLINE_L` (and
  `CAN_H_KLINE_K`/`CAN_L_KLINE_L`). No electrical change - schematics, PCB and
  netclass patterns were all updated together, so any board already built is
  unaffected.
- Archived board designs keep their original net and sheet names; only their
  READMEs use the corrected terminology.

## 01/09/2026

- VNA measured signal attenuation on a v3.1 board at -1.4dB which isn't great.
  Suspect it's because the SMA connectors are through-hole. in v3.3 I edited the
  footprint for the SMA and set the centre pins to connect to F.cu and B.cu only
  and put a keepout around them excluding In.1 and In.2.
- Increased width for the LTE RF trace to 0.36mm (was previously 0.292mm,
  incorrect)
- Increased width for the GPS TF trace to 0.306mm (was 0.292mm, incorrect)

Noting here for future reference:

Board: Rigid, 4 layers, 1.6 mm, inner 0.5 oz, outer 1 oz, unit mil. Stack-up:
JLC04161H-7628 (the "Standard" entry, what you get with "no requirement"):
L1 1 oz (0.035 mm), prepreg 7628 RC49% 0.2104 mm, L2 0.5 oz. Target 50 Ω,
signal layer L1, bottom ref L2, solder mask on.

GNSS feed (coplanar, top GND pour at 0.2 mm clearance)

Type: Coplanar Single Ended. Impedance trace to copper: 8 mil (0.2 mm). Result: trace width 12.04 mil = 0.306 mm.

LTE feed (plain microstrip, no top pour)

Type: Single Ended (Non coplanar). Result: trace width 14.12 mil = 0.359 mm.

## 01/09/2026

- Fixed the 0508 footprint in v3.3 to actually match the part dimensions
  properly, saving precious microns of board real estate.

## 31/08/2026

- Fixed decoupling and other cap discrepencies between the v3.1+ schematics and
  the associated BOMs/parts lists and changed the cap specs to match what v3.1
  was actually tested with. I made a silly mistake here thinking that the base
  spec for 100nF caps was fine even though I was testing with higher rated ones
  but turns out this was not the case. Builds are now standardised on a single
  50V 100nF X7R cap everywhere these are needed.
- Fixed various minor discrepencies between the schematics and README's for
  v3.1+

## 28/08/2026

- Added v3.3 with a fix for an L-line defect that could brick the MCU on earlier
  boards if L_SEND was used while the external L wire had been shorted to 12V.
  Also added a sensing capability for the L wire so this condition can be
  detected and also tuned the buck to turn off cleanly below ~4.3V and turn on
  again only above ~5.6V.

## 23/08/2026

- Updated sheet annotations for all boards v2.6+

## 23/08/2026

- v3.2 board prototype added with MCU over-voltage protection and I2C bus
  hardening

## 16/08/2026

- Added v3.1 board with more robust input protection, auxiliary power rail
  sensing/fault detection and a hardened antenna feed with 15R series resistance
  and ESD protection.
- Fixed bias tee cap placement order on all v2.5, v2.6 and v3.0 boards.

## 10/08/2026

- Fixed a few discrepencies in the BOM / parts lists

## 09/08/2026

- Added missing 510R pullup resistor to the L line on v2.5k and v2.6k
- Added v2.5k test results

## 08/08/2026

- Removed excessive stitching vias and optimised placements
- Removed unnecessary ENABLE resistor
- Other minor PCB layout tweaks

## 07/08/2026

- Fixed voltage spec of the buck output caps

## 05/08/2026

- Annotated the v3.0 schematics with specific part requirements
- Updated the v3.0 parts lists with the specific part requirements
- Relaxed tolerances where they don't matter

## 05/08/2026

- Added **l0destar v3.0** - the CAN and K-line variants consolidated onto a
  single PCB. Changes from v2.6:
  - Both the CAN and K-wire (ISO 14230-1 K-line) circuits are on the one board; either,
    neither or both can be populated, with the external connector pins and OBD
    power rails selected by shorting jumper pads (which double as power rail
    test points to save board space)
  - The L9637D was replaced with a TJA1027T LIN transceiver, dramatically
    simplifying the K-line circuit - the separate 5V buck converter and level
    shifter are gone
  - CAN transceiver swapped for a MAX33041EASA+ for more robust transient
    protection, with a pulldown added to STBY so the transceiver defaults to
    normal mode instead of floating
  - Auxiliary power MOSFETs and several ideal diodes replaced with load
    switches to simplify the system and reduce board footprint
  - OBD power rails are switched separately from the GPS power rail to cut
    power use during engine-off telemetry wakes
  - S2R2 increased to 10M and S4R2 to 100K for lower quiescent draw and more
    resilient ignition sensing at low system voltage

## 03/08/2026

- Minor PCB layout tweaks

## 02/08/2026

- Added **l0destar v2.6 micro (v2.6M)**. Changes from v2.5 micro:
  - Added stacked 47uF ceramic bulk capacitance (2220, 50V X7R,
    CKG57NX7R1H476M500JH) on the 12V input for additional resilience against
    automotive transient spikes
- Added **lodestar v2.6 K-line (v2.6K)**. Changes from v2.5 K-line:
  - Added stacked 47uF ceramic bulk capacitance (2220, 50V X7R,
    CKG57NX7R1H476M500JH) on the 12V input for additional resilience against
    automotive transient spikes
- Added **lodestar v2.6 CAN (v2.6C)**. Changes from v2.5 CAN:
  - Added stacked 47uF ceramic bulk capacitance (2220, 50V X7R,
    CKG57NX7R1H476M500JH) on the 12V input for additional resilience against
    automotive transient spikes

## 01/08/2026

- Added **l0destar v2.5 micro (v2.5M)** - a major redesign of the mini
  prototype:
  - Dramatically smaller PCB footprint
  - Switched to a 4-layer stackup for simpler routing
  - Default passive size reduced from 0805 to 0402, bumped to 0603/0805 only
    where required by specification
  - Removed the large aluminium polymer caps; buck output cap replaced with
    2x 1210 ceramic 220uF for much lower ESR
  - Sleep-mode power consumption optimised - estimated quiescent draw with the
    accelerometer armed is ~370 µA
  - Removed the relay power control circuit; with quiescent current this low
    it's unnecessary (the 12V rail can be fed directly from ignition if
    ignition-only power is wanted)
  - Component specifications reviewed for automotive use and indicated in the
    BOM; input stage MOSFETs and TVS tuned for smaller footprint and more
    appropriate ratings
  - Component vias dogleg-routed deliberately to keep fabrication cost down
- Fixed the input TVS part on v2.5 micro: PTVS30VS1UTR → PTVS33VS1UTR
- Fixed reference designators in the v2.5 micro schematics
- Added **l0destar v2.5K** - K-wire variant of v2.5 with the K-line
  interface (L9637D), a second LT8609 providing a switchable 5V rail, a
  switchable auxiliary 12V rail on the k-enable signal, and L-line pulldown
- Added **l0destar v2.5C** - CAN-bus variant of v2.5 with a CAN interface
  including standby control via the XSTBY signal

## 20/07/2026

- v2.1 mini: fixed the status LED footprint and mounted 5 LEDs vertically

## 19/07/2026

- Added **l0destar v2.1** and **l0destar v2.1 mini** (developed from
  prototype v2.0):
  - v2.1: CAN + K-wire interfaces, dual buck converters, switchable
    auxiliary 3.3V/5V/12V rails, six general-purpose 0-30V AIO pins
  - v2.1 mini: same board with the CAN, K-wire and AIO circuitry removed
    for a smaller footprint and simpler construction; later bench-tested with
    ~1 mA sleep current
- Removed earlier prototypes that were either failed or non-viable:
  **prototype v1.0**, **v1.1 K-wire handsolder**, **v1.1 CAN handsolder**
  and **prototype v2.0**

## 15/07/2026

- Added **prototype v2.0** - first fully integrated standalone design (no
  breakout modules): onboard GPS antenna bias tee with SMA/u.FL connectors,
  AIO pins, integrated CAN and K-wire circuits, status LED and test points.
  Superseded by v2.1 four days later.

## 25/06/2026

- Documented known issues found while testing the v1.1 K-wire handsolder
  board:
  - With AUX_SW low the +5V_AUX rail reads ~2.8V due to 12V backfeeding
    through the L9637D into the rail
  - Trace clearance too low in several places, making the board very hard to
    hand-assemble without bridging nets

## 13/06/2026

- Added **prototype v1.1 CAN handsolder** - CAN version of the hand-solderable
  tracker (MCP2518FD-based CAN interface in place of the K-line circuit)

## 12/06/2026

- Added **bench_test_iso9141** - bench development board for the nRF9151 Dev
  Kit with dual L9637D transceivers and level shifters; a 3V relay gates all
  power rails behind the DK's 3.3V supply so nothing is live when the DK is
  off
- Added **bench_test_can** - CAN version of the bench board with MikroBUS
  headers for the MIKROE-2379 CAN-FD Click
- Added **prototype v1.1 K-wire handsolder** - first standalone
  hand-buildable tracker using the Makerdiary nRF9151 Connect Kit: 4.2V buck
  into the battery connector (USB-C usable without removing power), 12V
  live/ignition inputs with TVS and reverse polarity protection, relay-based
  power source switching, INA228 voltage monitoring, L9637D with 5V buck,
  switchable auxiliary rails, ASM330LHHXG1TR IMU, 2200uF bulk cap for
  cranking

## 09/06/2026

- v1.0: replaced the voltage divider that derives the ignition signal with a
  MOSFET gating the 3.3V rail. Previously the divider produced ~9V clamped by
  a 3.3V zener - a failed-open zener would have put 9V straight onto the MCU
  pin. The MOSFET inverts the signal (high when ignition is off), which is
  acceptable and matches similar devices

## 07/06/2026

- v1.0: fixed the ignition sense divider to give a solid 3.3V/0V signal - the
  nRF9151 docs warn against leaving signal pins floating between logic levels
- v1.0: added a 4.2V buck converter with an LM66100 ideal diode to power the
  Makerdiary ConnectKit via its battery connector, so the device can be
  hardwired to vehicle power while still allowing USB connection for
  programming (powering VBUS and USB simultaneously is explicitly
  disallowed)

## 30/05/2026

- Added **l0destar v1.0 prototype** - initial schematics and board design

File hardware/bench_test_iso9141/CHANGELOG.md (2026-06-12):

# Changelog

## 12/06/2026

- Initial release

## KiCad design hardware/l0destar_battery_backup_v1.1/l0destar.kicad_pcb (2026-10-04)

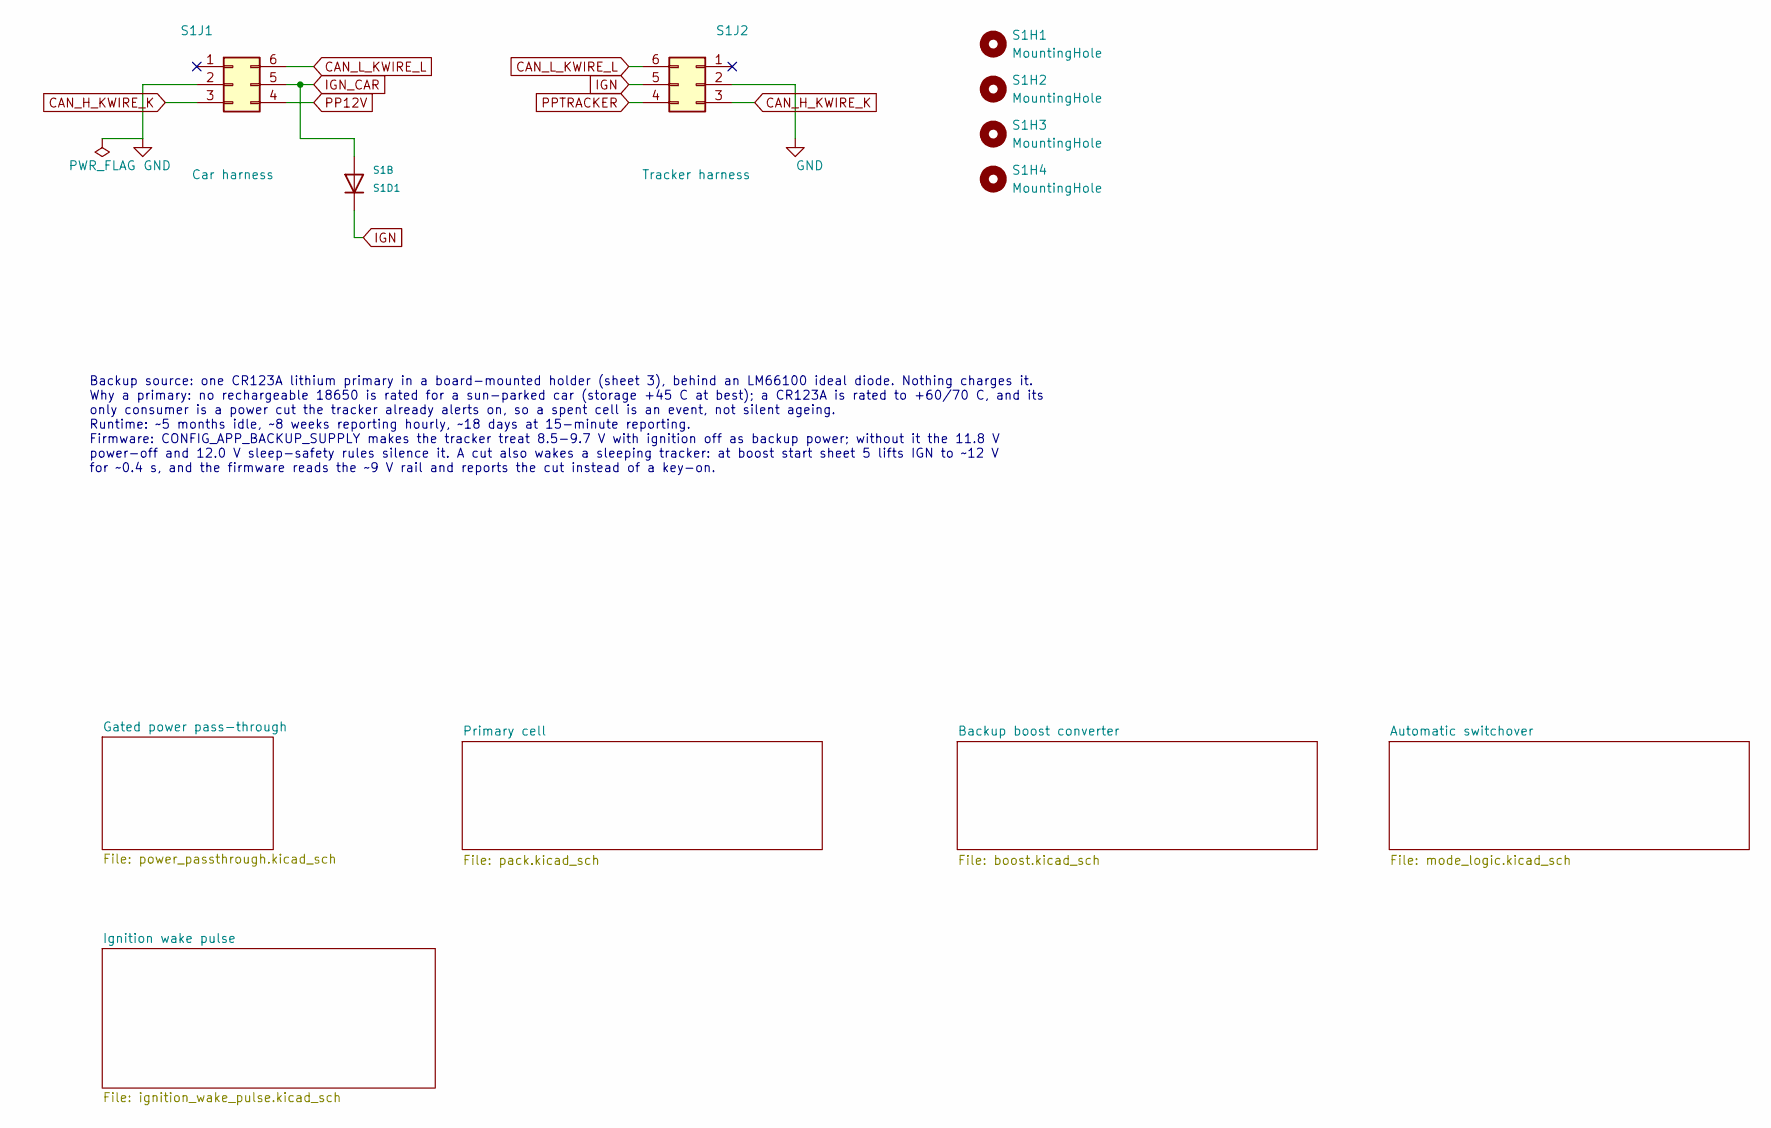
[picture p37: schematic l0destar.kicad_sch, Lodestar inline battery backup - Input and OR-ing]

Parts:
S1D1: S1B; D_SMA; MPN S1B-13-F; LCSC C156295
S1H1, S1H2, S1H3, S1H4: MountingHole; MountingHole_2.2mm_M2
S1J1: Car harness; Molex_Micro-Fit_3.0_43045-0600_2x03_P3.00mm_Horizontal
S1J2: Tracker harness; Molex_Micro-Fit_3.0_43045-0600_2x03_P3.00mm_Horizontal

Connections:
CAN_H_KWIRE_K: S1J1.3, S1J2.3
CAN_L_KWIRE_L: S1J1.6, S1J2.6
GND: S1J1.2, S1J2.2; also elsewhere on the board
IGN: S1D1.1 (K), S1J2.5; also elsewhere on the board
IGN_CAR: S1D1.2 (A), S1J1.5
PP12V: S1J1.4; also elsewhere on the board
PPTRACKER: S1J2.4; also elsewhere on the board

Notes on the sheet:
Backup source: one CR123A lithium primary in a board-mounted holder (sheet 3), behind an LM66100 ideal diode. Nothing charges it. Why a primary: no rechargeable 18650 is rated for a sun-parked car (storage +45 C at best); a CR123A is rated to +60/70 C, and its only consumer is a power cut the track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

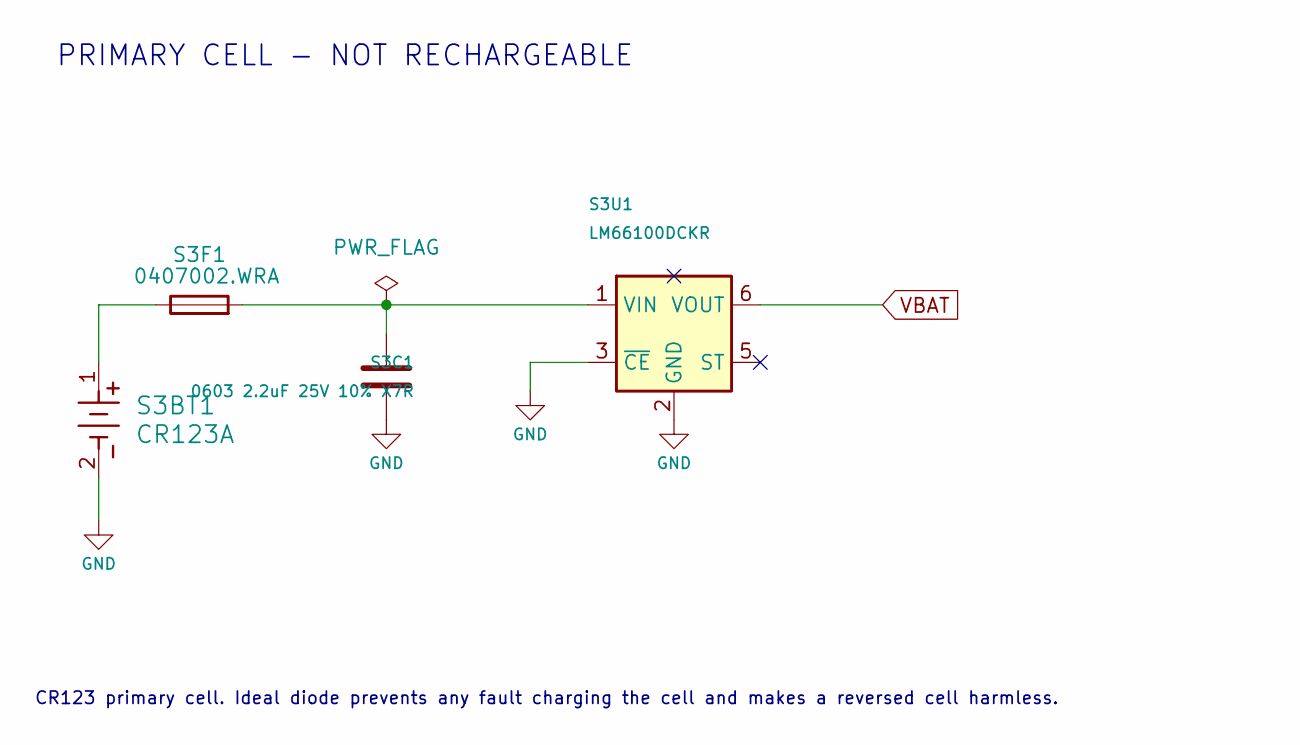
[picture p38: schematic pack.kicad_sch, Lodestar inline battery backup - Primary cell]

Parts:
S3BT1: CR123A; 1051_KEY; MPN 1051
S3C1: 0603 2.2uF 25V 10% X7R; C_0603_1608Metric; MPN GRM188Z71E225KE43D
S3F1: 0407002.WRA; Fuse_1206_3216Metric; MPN 0407002.WRA
S3U1: LM66100DCKR; SOT-363_SC-70-6; MPN LM66100DCKR

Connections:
GND: S3BT1.2, S3C1.2, S3U1.2 (GND), S3U1.3 (~CE); also elsewhere on the board
unnamed: S3BT1.1, S3F1.1
unnamed: S3C1.1, S3F1.2, S3U1.1 (VIN)
VBAT: S3U1.6 (VOUT); also elsewhere on the board

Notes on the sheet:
PRIMARY CELL - NOT RECHARGEABLE
CR123 primary cell. Ideal diode prevents any fault charging the cell and makes a reversed cell harmless.

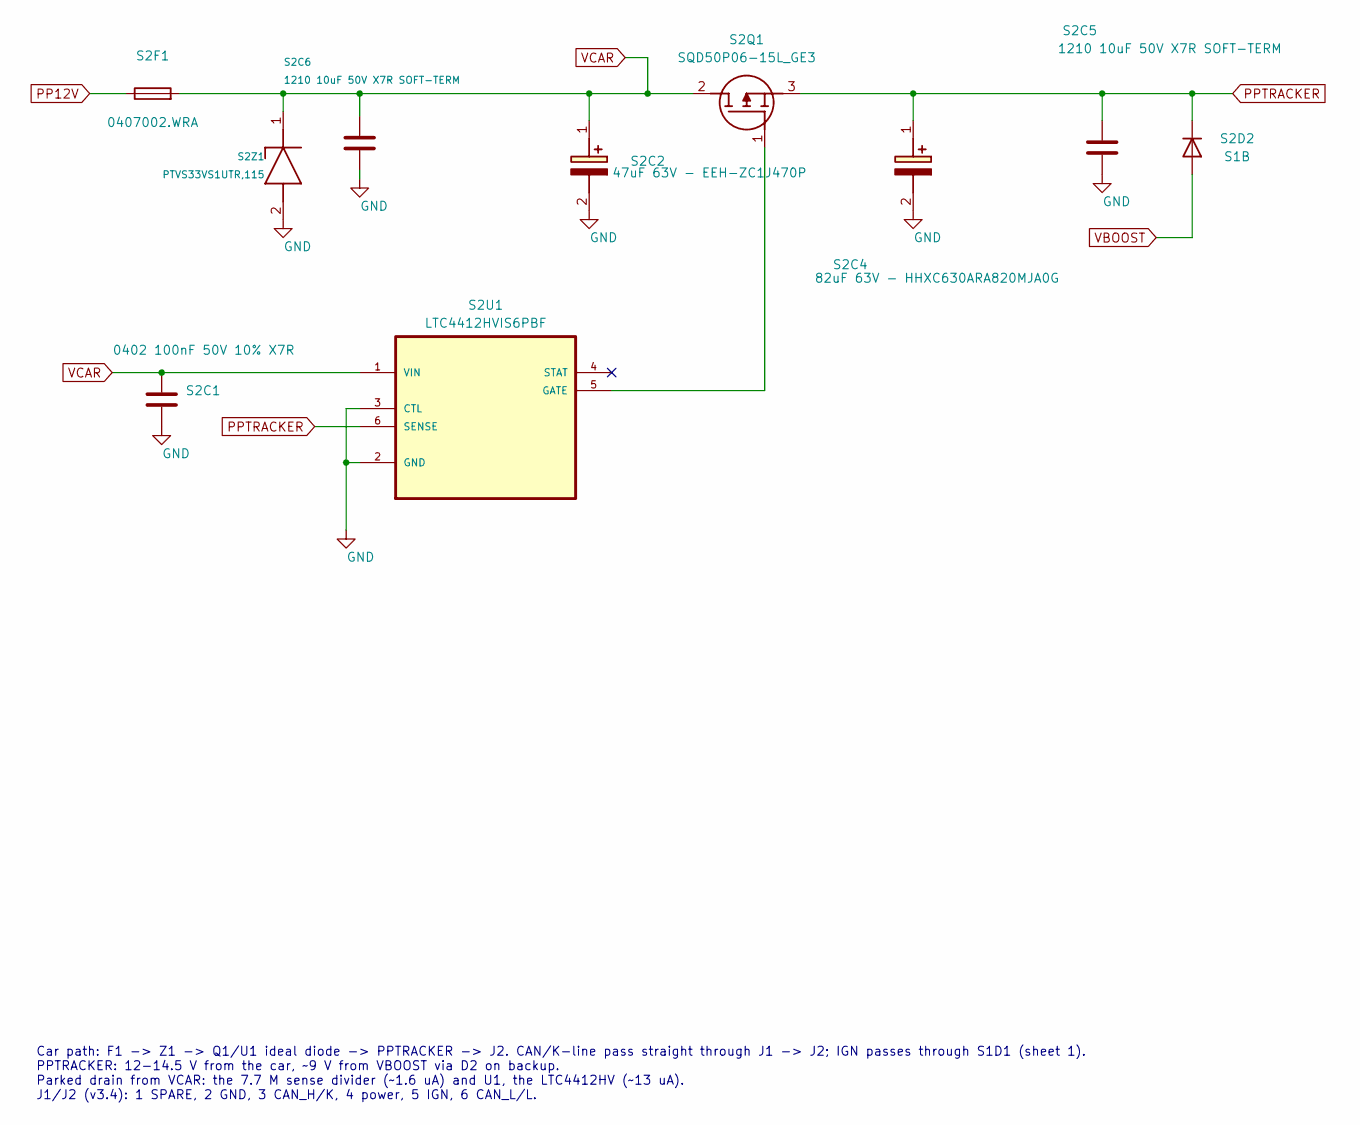
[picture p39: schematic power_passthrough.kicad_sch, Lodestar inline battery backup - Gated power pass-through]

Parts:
S2C1: 0402 100nF 50V 10% X7R; C_0402_1005Metric; MPN GRM155R71H104KE14D
S2C2: 47uF 63V - EEH-ZC1J470P; EEH_ZC1J470P; MPN EEH-ZC1J470P; LCSC C454353
S2C4: 82uF 63V - HHXC630ARA820MJA0G; HHXC630ARA820MJA0G; MPN HHXC630ARA820MJA0G; LCSC C2161798
S2C5, S2C6: 1210 10uF 50V X7R SOFT-TERM; C_1210_3225Metric; MPN MCJCU32MLB7106KPPDT1
S2D2: S1B; D_SMA; MPN S1B-13-F; LCSC C156295
S2F1: 0407002.WRA; Fuse_1206_3216Metric; MPN 0407002.WRA
S2Q1: SQD50P06-15L_GE3; SQD50P06-15L_GE3_tight; Manufacturer_Part_Number SQD50P06-15L_GE3
S2U1: LTC4412HVIS6PBF; MPN LTC4412HVIS6#PBF
S2Z1: PTVS33VS1UTR,115; Nexperia_CFP3_SOD-123W; MPN PTVS33VS1UTR,115

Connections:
GND: S2C1.2, S2C2.2 (-), S2C4.2 (-), S2C5.2, S2C6.2, S2U1.2 (GND), S2U1.3 (CTL), S2Z1.2 (A); also elsewhere on the board
unnamed: S2Q1.1 (G), S2U1.5 (GATE)
PP12V: S2F1.1; also elsewhere on the board
PPTRACKER: S2C4.1 (+), S2C5.1, S2D2.1 (K), S2Q1.3 (S), S2U1.6 (SENSE); also elsewhere on the board
VBOOST: S2D2.2 (A); also elsewhere on the board
VCAR: S2C1.1, S2C2.1 (+), S2C6.1, S2F1.2, S2Q1.2 (D), S2U1.1 (VIN), S2Z1.1 (K); also elsewhere on the board

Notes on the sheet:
Car path: F1 -> Z1 -> Q1/U1 ideal diode -> PPTRACKER -> J2. CAN/K-line pass straight through J1 -> J2; IGN passes through S1D1 (sheet 1). PPTRACKER: 12-14.5 V from the car, ~9 V from VBOOST via D2 on backup. Parked drain from VCAR: the 7.7 M sense divider (~1.6 uA) and U1, the LTC4412HV (~13 uA). J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

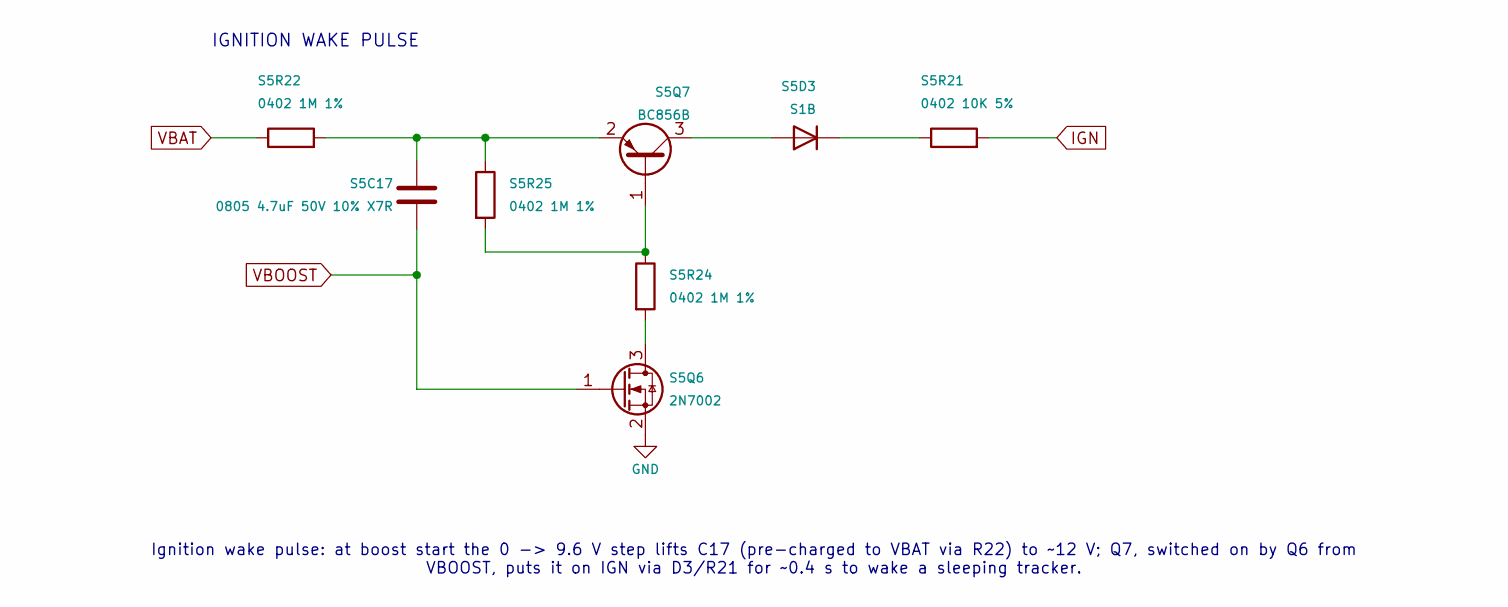
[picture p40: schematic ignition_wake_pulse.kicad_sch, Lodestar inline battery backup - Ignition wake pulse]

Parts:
S5C17: 0805 4.7uF 50V 10% X7R; C_0805_2012Metric; MPN GRM21BZ71H475KE15K
S5D3: S1B; D_SMA; MPN S1B-13-F; LCSC C156295
S5Q6: 2N7002; SOT-23; MPN 2N7002
S5Q7: BC856B; SOT-23; MPN BC856B
S5R21: 0402 10K 5%; R_0402_1005Metric
S5R22, S5R24, S5R25: 0402 1M 1%; R_0402_1005Metric

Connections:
GND: S5Q6.2 (S); also elsewhere on the board
IGN: S5R21.2; also elsewhere on the board
unnamed: S5D3.2 (A), S5Q7.3 (C)
unnamed: S5D3.1 (K), S5R21.1
unnamed: S5Q6.3 (D), S5R24.2
unnamed: S5Q7.1 (B), S5R24.1, S5R25.2
unnamed: S5C17.1, S5Q7.2 (E), S5R22.2, S5R25.1
VBAT: S5R22.1; also elsewhere on the board
VBOOST: S5C17.2, S5Q6.1 (G); also elsewhere on the board

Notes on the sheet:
IGNITION WAKE PULSE
Ignition wake pulse: at boost start the 0 -> 9.6 V step lifts C17 (pre-charged to VBAT via R22) to ~12 V; Q7, switched on by Q6 from VBOOST, puts it on IGN via D3/R21 for ~0.4 s to wake a sleeping tracker.

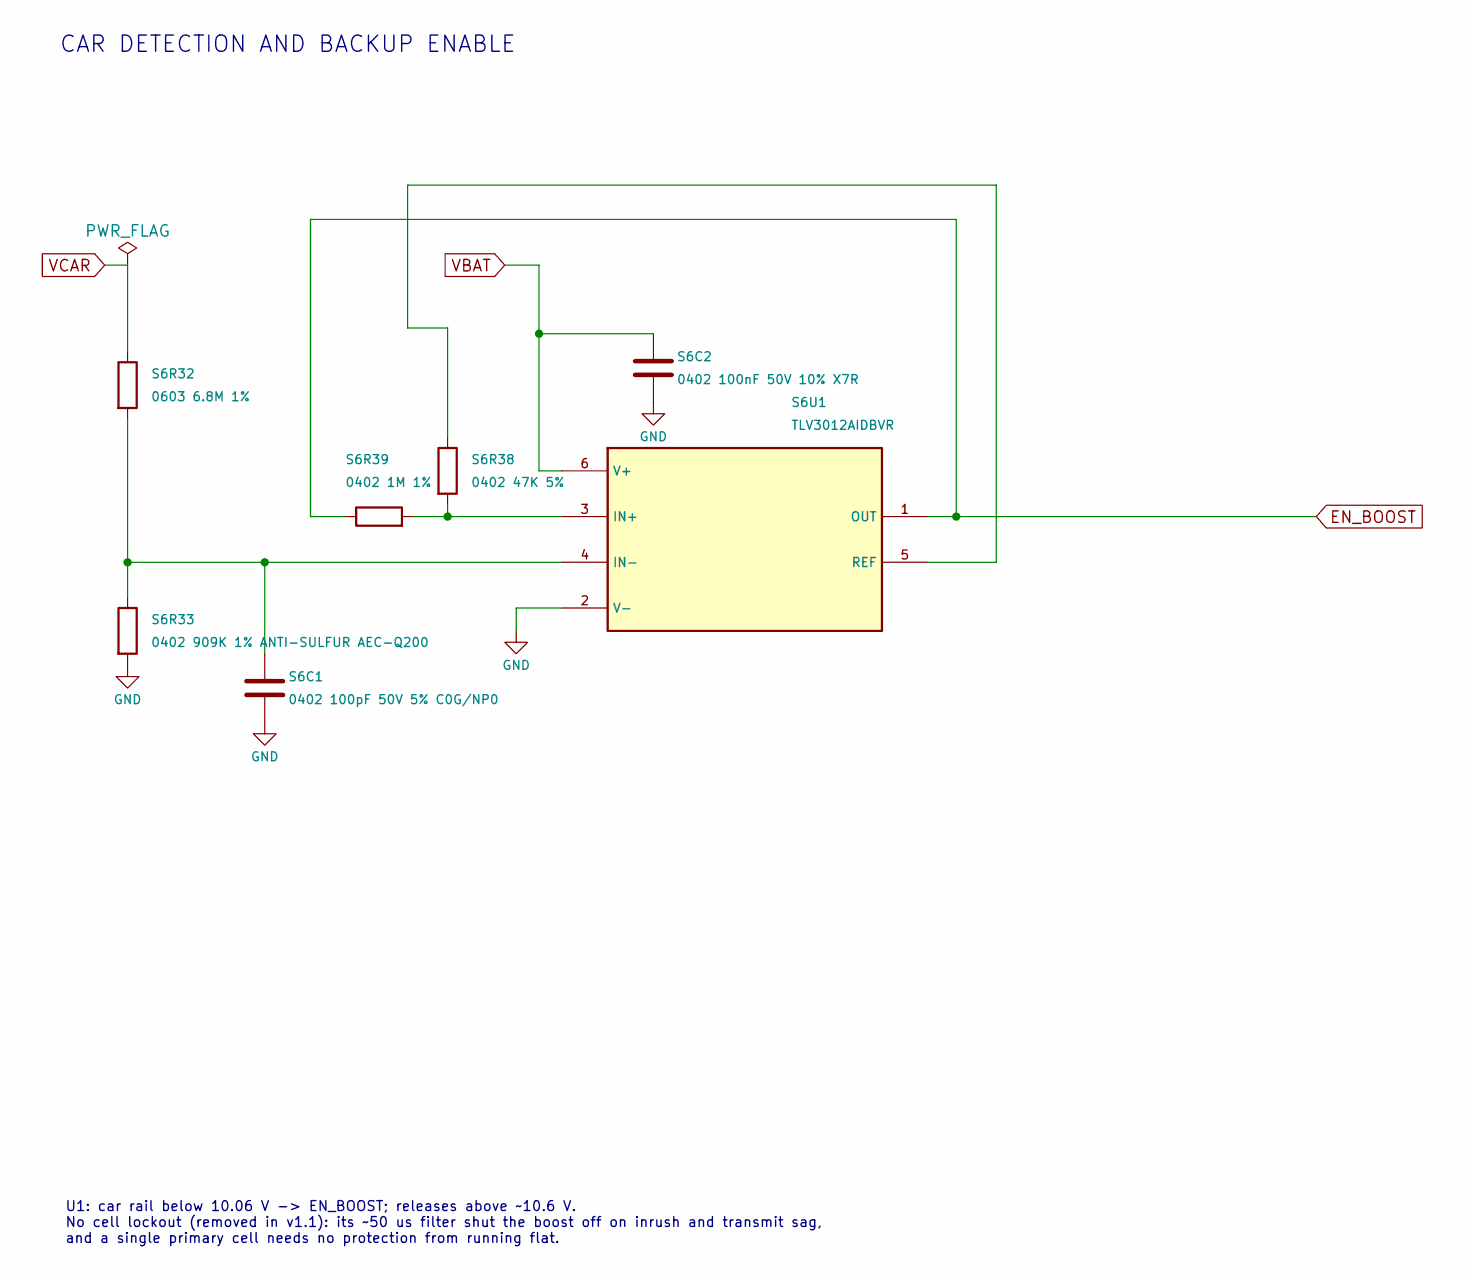
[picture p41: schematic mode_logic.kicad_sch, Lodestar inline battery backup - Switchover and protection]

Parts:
S6C1: 0402 100pF 50V 5% C0G/NP0; C_0402_1005Metric; MPN 0402N101J500CT
S6C2: 0402 100nF 50V 10% X7R; C_0402_1005Metric; MPN GRM155R71H104KE14D
S6R32: 0603 6.8M 1%; R_0603_1608Metric
S6R33: 0402 909K 1% ANTI-SULFUR AEC-Q200; R_0402_1005Metric; MPN AF0402FR-07909KL
S6R38: 0402 47K 5%; R_0402_1005Metric
S6R39: 0402 1M 1%; R_0402_1005Metric
S6U1: TLV3012AIDBVR; SOT-23-6; MPN TLV3012AIDBVR

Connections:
EN_BOOST: S6R39.1, S6U1.1 (OUT); also elsewhere on the board
GND: S6C1.2, S6C2.2, S6R33.2, S6U1.2 (V-); also elsewhere on the board
unnamed: S6R38.2, S6R39.2, S6U1.3 (IN+)
unnamed: S6C1.1, S6R32.2, S6R33.1, S6U1.4 (IN-)
unnamed: S6R38.1, S6U1.5 (REF)
VBAT: S6C2.1, S6U1.6 (V+); also elsewhere on the board
VCAR: S6R32.1; also elsewhere on the board

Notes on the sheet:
CAR DETECTION AND BACKUP ENABLE
U1: car rail below 10.06 V -> EN_BOOST; releases above ~10.6 V. No cell lockout (removed in v1.1): its ~50 us filter shut the boost off on inrush and transmit sag, and a single primary cell needs no protection from running flat.

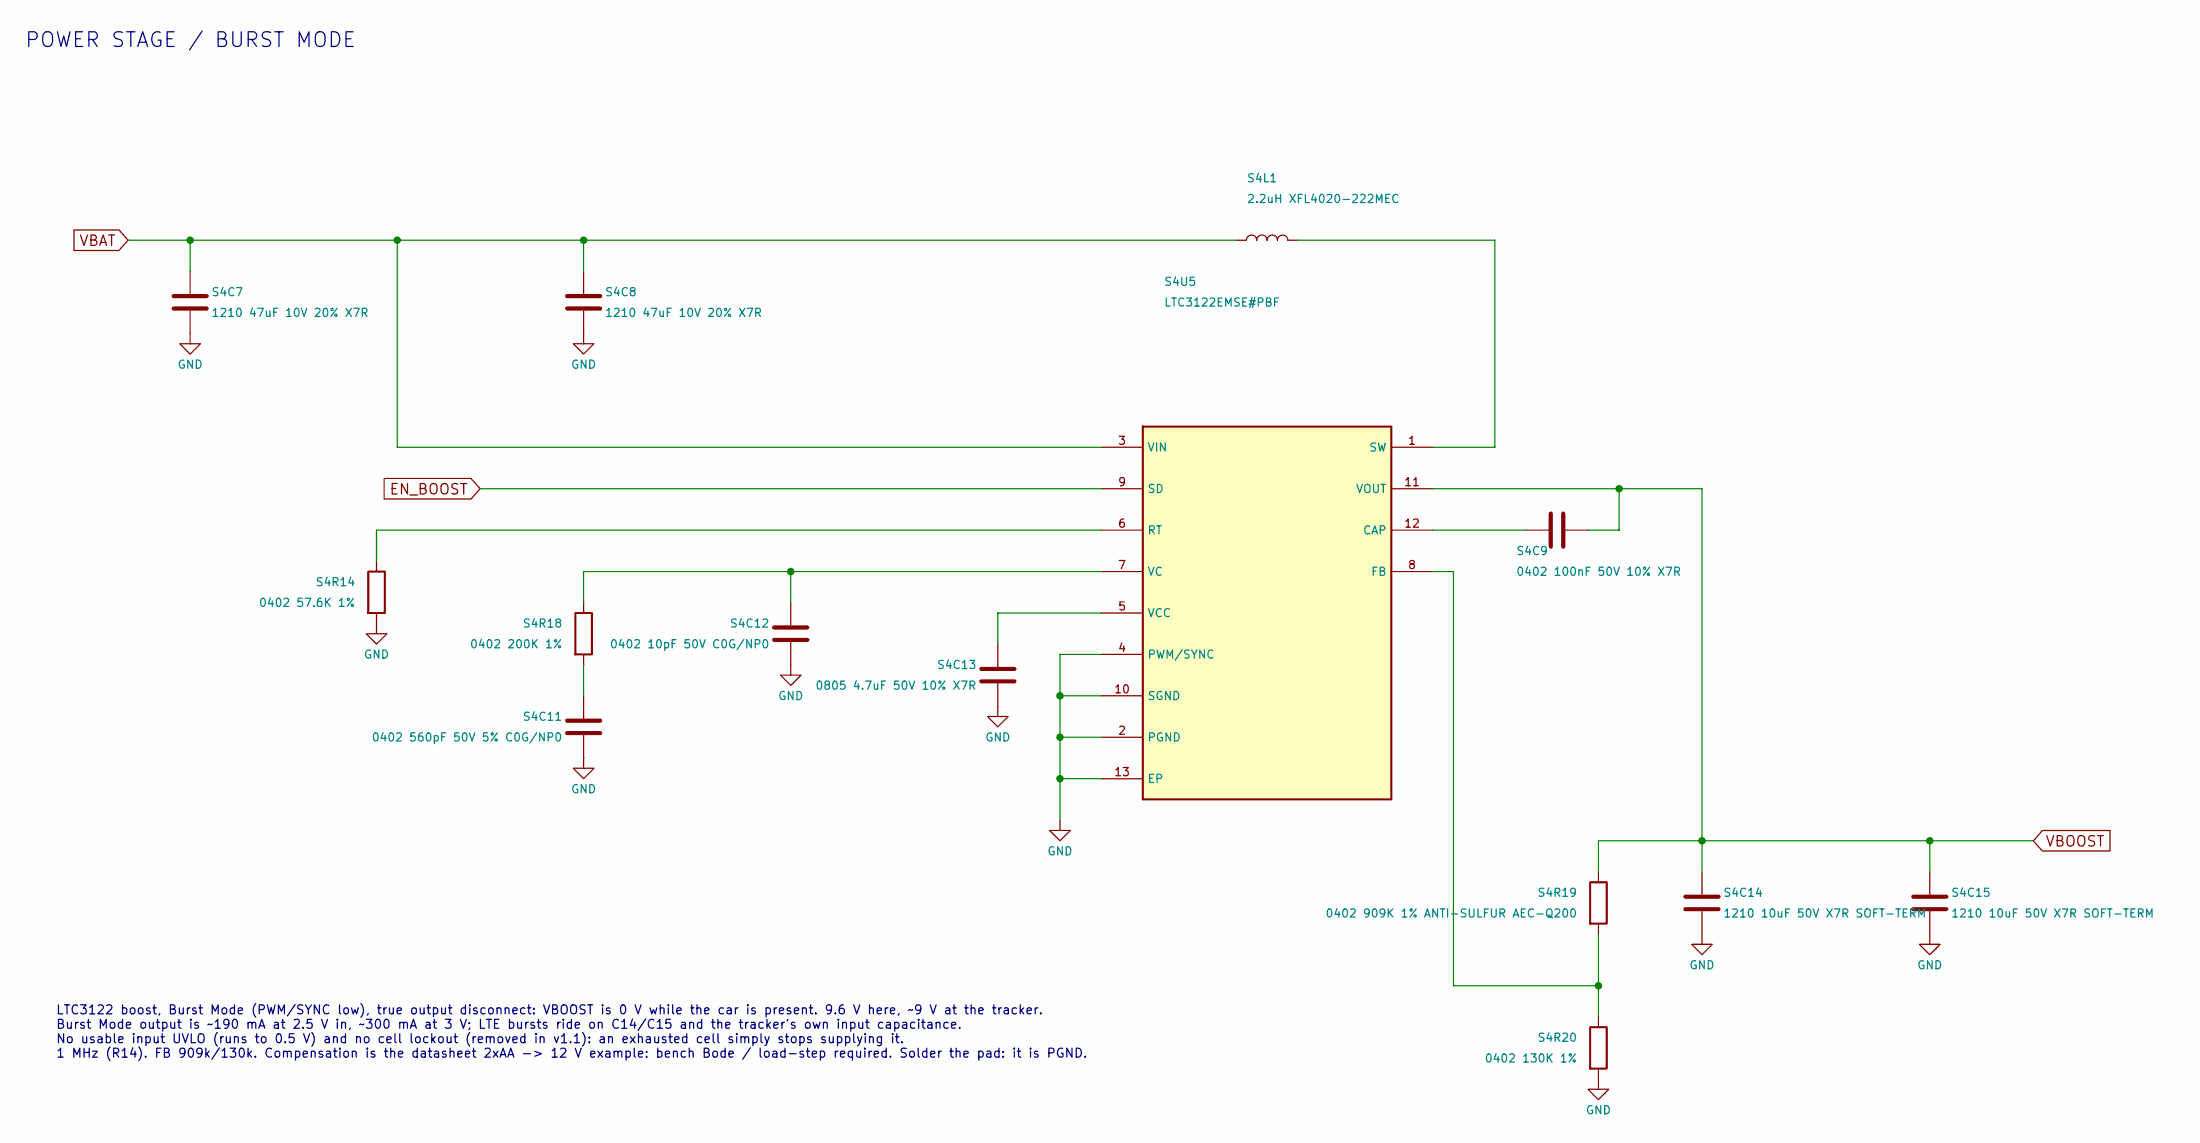
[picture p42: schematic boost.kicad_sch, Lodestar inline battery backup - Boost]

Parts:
S4C7, S4C8: 1210 47uF 10V 20% X7R; C_1210_3225Metric; MPN CL32B476MPJNNNE
S4C9: 0402 100nF 50V 10% X7R; C_0402_1005Metric; MPN GRM155R71H104KE14D
S4C11: 0402 560pF 50V 5% C0G/NP0; C_0402_1005Metric
S4C12: 0402 10pF 50V C0G/NP0; C_0402_1005Metric; MPN GRM1555C1H100JA01D
S4C13: 0805 4.7uF 50V 10% X7R; C_0805_2012Metric; MPN GRM21BZ71H475KE15K
S4C14, S4C15: 1210 10uF 50V X7R SOFT-TERM; C_1210_3225Metric; MPN MCJCU32MLB7106KPPDT1
S4L1: 2.2uH XFL4020-222MEC; IND_XFL4020-222ME; MPN XFL4020-222MEC
S4R14: 0402 57.6K 1%; R_0402_1005Metric
S4R18: 0402 200K 1%; R_0402_1005Metric
S4R19: 0402 909K 1% ANTI-SULFUR AEC-Q200; R_0402_1005Metric; MPN AF0402FR-07909KL
S4R20: 0402 130K 1%; R_0402_1005Metric
S4U5: LTC3122EMSE#PBF; MSOP-12-1EP_3x4.039mm_P0.65mm_EP1.651x2.845mm; MPN LTC3122EMSE#PBF

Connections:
EN_BOOST: S4U5.9 (SD); also elsewhere on the board
GND: S4C7.2, S4C8.2, S4C11.2, S4C12.2, S4C13.2, S4C14.2, S4C15.2, S4R14.2, S4R20.2, S4U5.2 (PGND), S4U5.4 (PWM/SYNC), S4U5.10 (SGND), S4U5.13 (EP); also elsewhere on the board
unnamed: S4C11.1, S4R18.2
unnamed: S4C9.1, S4U5.12 (CAP)
unnamed: S4R19.2, S4R20.1, S4U5.8 (FB)
unnamed: S4R14.1, S4U5.6 (RT)
unnamed: S4L1.2, S4U5.1 (SW)
unnamed: S4C12.1, S4R18.1, S4U5.7 (VC)
unnamed: S4C13.1, S4U5.5 (VCC)
VBAT: S4C7.1, S4C8.1, S4L1.1, S4U5.3 (VIN); also elsewhere on the board
VBOOST: S4C9.2, S4C14.1, S4C15.1, S4R19.1, S4U5.11 (VOUT); also elsewhere on the board

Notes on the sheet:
LTC3122 boost, Burst Mode (PWM/SYNC low), true output disconnect: VBOOST is 0 V while the car is present. 9.6 V here, ~9 V at the tracker. Burst Mode output is ~190 mA at 2.5 V in, ~300 mA at 3 V; LTE bursts ride on C14/C15 and the tracker's own input capacitance. No usable input UVLO (runs to 0.5 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
POWER STAGE / BURST MODE

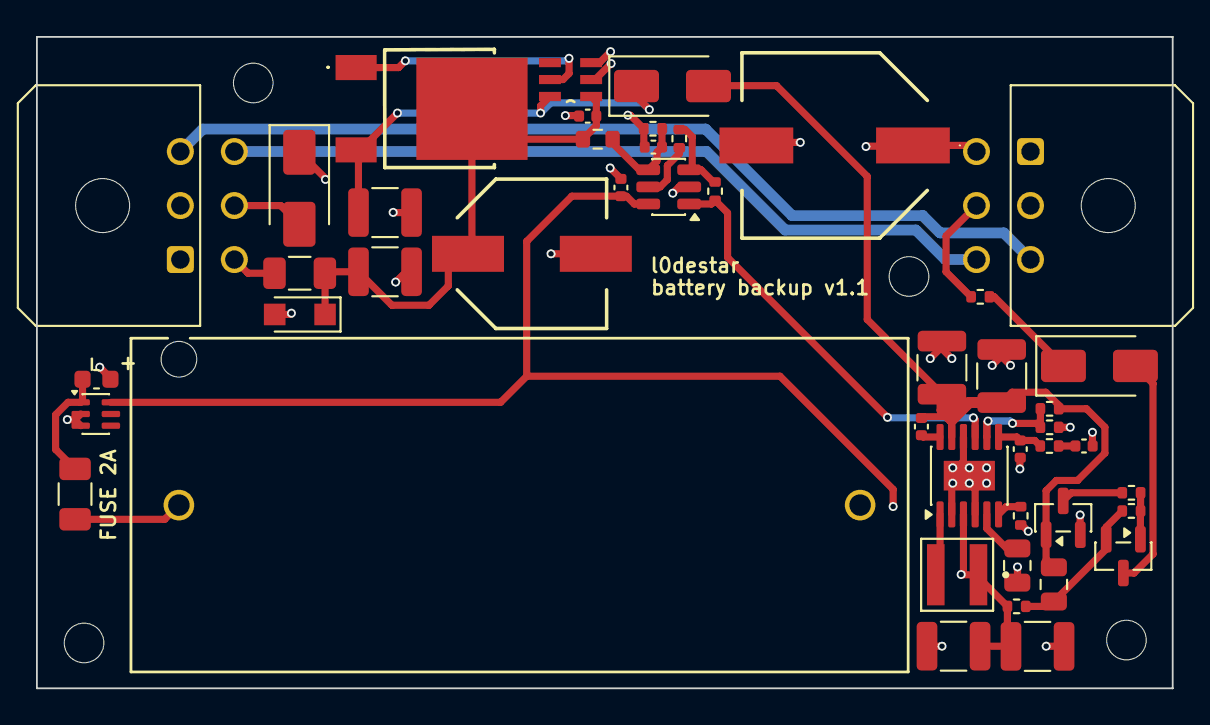
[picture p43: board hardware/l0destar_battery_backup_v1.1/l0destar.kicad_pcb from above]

Board: 4 copper layers, 63.1 x 36.2 mm, 50 parts (0 on the bottom side), 29 nets.

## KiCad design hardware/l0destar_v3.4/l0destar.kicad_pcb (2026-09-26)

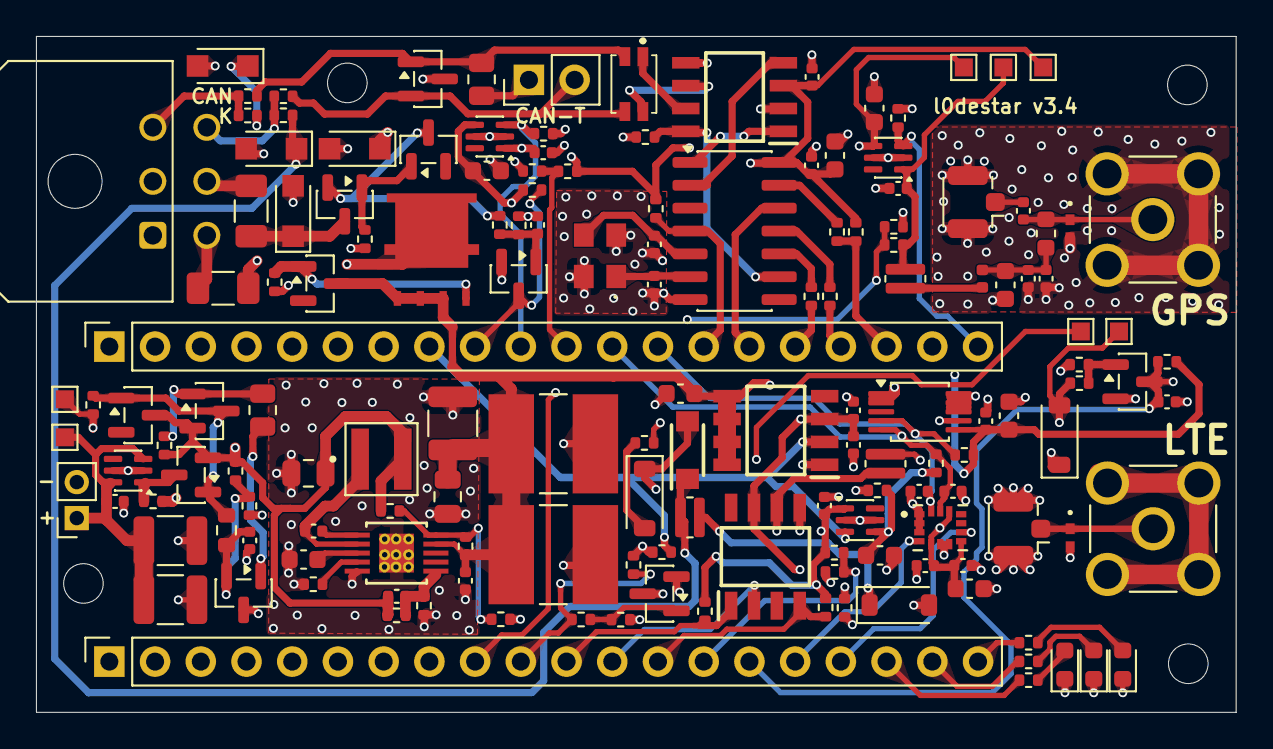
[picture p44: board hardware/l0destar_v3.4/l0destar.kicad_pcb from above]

Board: 4 copper layers, 66.7 x 37.5 mm, 160 parts (0 on the bottom side), 85 nets.

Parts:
H1, H2, H3, H4: MountingHole; MountingHole_2.2mm_M2
S1C1, S3C2, S4C1, S6C1, S6C8, S7C2, S7C4, S7C9, S8C1, S8C3, S9C1, S9C4, S10C1: 0402 100nF 50V 10% X7R; C_0402_1005Metric
S1J1: Main connector; Molex_Micro-Fit_3.0_43045-0600_2x03_P3.00mm_Horizontal
S1J2: Conn_01x20_Socket; MakerDiary_nRF9151_ConnectKit_PinHeader_1-20_tight
S1J3: Conn_01x20_Socket_21-40; MakerDiary_nRF9151_ConnectKit_PinHeader_21-40
S1J4: +; MakerDiary2PinHeader
S1R1, S1R2: 0402 1.8K 1%; R_0402_1005Metric
S1R3, S1R4, S1R5, S2R2, S7R1, S7R3, S7R6, S7R7, S7R8, S10R6: 0402 100K 5%; R_0402_1005Metric
S2C1, S2C2: 47uF 2220 50V 20% X7R; CAPC6050X550N
S2C3: 10uF 1210 50V 10% X7R SOFT TERMINATION; C_1210_3225Metric
S2D1, S2D3, S11D1: BZX84C15; SOT-23
S2D2, S2D4, S10D2, S10D4: PTVS33VS1UTR,115; Nexperia_CFP3_SOD-123W
S2F1, S2F2: 0407002.WRA; Fuse_1206_3216Metric
S2Q1, S11Q1: SQ2361CES-T1_BE3; SOT-23
S2Q2: SQJ457EP-T1_BE3; POWERPAK-SO-8-4
S2R1, S7R2, S7R4, S7R9: 0402 1M 5%; R_0402_1005Metric
S3C1, S6C2, S7C1, S7C3, S7C8, S15C4: 0603 2.2uF 25V 10% X7R; C_0603_1608Metric
S3U1: INA238; TSSOP-10_3x3mm_P0.5mm
S4Q1, S7Q1, S10Q1: 2N7002; SOT-23
S4R1, S7R5: 0402 180K 5%; R_0402_1005Metric
S4R2, S4R3: 0402 56K 5%; R_0402_1005Metric
S5R1, S5R2, S5R3, S5R4, S5R5: 0402 0R; R_0402_1005Metric
S6C3: 0805 4.7uF 50V 10% X7R; C_0805_2012Metric
S6C4: 0402 10pF 50V C0G/NP0; C_0402_1005Metric
S6C5: 0805 22uF 10V 20% X7R; C_0805_2012Metric
S6L1: XFL4020-222ME; IND_XFL4020-222ME
S6R1: 0402 18.2K 1%; R_0402_1005Metric
S6R2: 0402 226K 1% ANTI-SULFUR AEC-Q200; R_0402_1005Metric
S6R3, S10R9, S11R5: 0402 1M 1% ANTI-SULFUR AEC-Q200; R_0402_1005Metric
S6R4: 0402 0R JUMPER OR 1M 1% ANTI-SULFUR AEC-Q200; R_0402_1005Metric
S6R5: DNP 0402 243K 1% ANTI-SULFUR AEC-Q200; R_0402_1005Metric
S6R6: DNP 0402 3.92M 1%; R_0402_1005Metric
S6U1: LT8609AIMSE_PBF; LT8609AIMSE_WITH_GROUND_VIAS
S7C5, S7C7: 0402 1nF 50V 10% X7R; C_0402_1005Metric
S7C6: 0603 220nF 50V 10% X7R; C_0603_1608Metric
S7U1, S7U2, S7U4: SiP32431DR3; SOT-363_SC-70-6
S7U3: ITS4060SSJNXUMA1
S8C2, S9C5: 0603 10uF 10V 20% X7R; C_0603_1608Metric
S8C4, S8C5, S15C2: 0402 100pF 50V 5% C0G/NP0; C_0402_1005Metric
S8R1: 0402 FB BLM15AG601SH1D; R_0402_1005Metric
S8U1: ASM330LHHXTR; XDCR_ASM330LHHXTR
S9C2, S9C3: 0402 27pF 10V 5% C0G/NP0; C_0402_1005Metric
S9D1: NUP2105L; SOT-23
S9FL1: ACT1210-101-2P-TL00; ACT12101012PTL00_tight
S9J1: Conn_01x02_Pin; PinHeader_1x02_P2.54mm_Vertical_Tight
S9R1, S9R2, S9R4, S10R1, S10R2, S10R5: 0402 10K 5%; R_0402_1005Metric
S9R3: 0805 120R 5% 0.5W; R_0805_2012Metric
S9R5, S13R1, S13R2, S13R3: 0402 1K 5%; R_0402_1005Metric
S9R6, S9R7: 0402 220R 5%; R_0402_1005Metric
S9U1: TCAN3414DR; SOIC127P600X175-8N
S9U2: MCP2518FD-xQBB; SOIC-14_3.9x8.7mm_P1.27mm
S9Y1: ECS-400-18-33-JGN-TR3; ECS4001833JGNTR3
S10D1, S10D3, S10D5: 1N4148W; D_SOD-123
S10R3, S10R4: 0508 510R 5% 1W; R_0508_1220Metric_WideTerminal_Tight
S10R7, S10R8: 0402 47K 5%; R_0402_1005Metric
S10U1: TJA1027T_20,118; TJA1027T_20_118
S10U2: AL5809-90P1-7
S11C1, S11C2: 1210 47uF 10V 20% X7R; C_1210_3225Metric
S11C3: 0402 3.3pF 50V C0G/NP0 +/- 0.25pF; C_0402_1005Metric
S11Q2: BC856BLT1G; SOT-23
S11R1: 0402 10K 1%; R_0402_1005Metric
S11R2: 0402 1M 1%; R_0402_1005Metric
S11R3: 0603 33M 5%; R_0603_1608Metric
S11R4: 0805 15K 1% ANTI-SULFUR AEC-Q200; R_0805_2012Metric
S11R6: 0402 1.05M 1%; R_0402_1005Metric
S11U1: LM66100DCK; SOT-363_SC-70-6
S11U2: ATL431BQDBZR; SOT-23
S12TP1: GND; TestPoint_Pad_1.0x1.0mm
S12TP2: 4.2V protected; TestPoint_Pad_1.0x1.0mm
S12TP3: 3.3V; TestPoint_Pad_1.0x1.0mm
S12TP4: 3.3V GPS; TestPoint_Pad_1.0x1.0mm
S12TP5: 3.3V CAN; TestPoint_Pad_1.0x1.0mm
S12TP6: 3.3V K; TestPoint_Pad_1.0x1.0mm
S12TP7: 12V K; TestPoint_Pad_1.0x1.0mm
S13D1, S13D2, S13D3: Wurth 150060RS86000; LED_0603_1608Metric
S15C1: 0402 47pF 50V 5% C0G/NP0; C_0402_1005Metric
S15C3: 0402 10nF 50V 5% C0G/NP0; C_0402_1005Metric
S15D1, S15D2: DNP - TPD1E05U06DPYR; DIO_TPD1E05U06DPYR
S15FB1: 0402 600R 0.5A 25%; L_0402_1005Metric
S15J1: GPS_UFL; U.FL_Hirose_U.FL-R-SMT-1_Vertical
S15J2: GPS_SMA; SAMTEC_SMA-J-P-H-RA-TH1_centrepin
S15J3: GSM_UFL; U.FL_Hirose_U.FL-R-SMT-1_Vertical
S15J4: GSM_SMA; SAMTEC_SMA-J-P-H-RA-TH1_centrepin
S15L1: LQW18AN68NJ00D; L_0603_1608Metric
S15R1: 0508 1W 5% 15R; R_0508_1220Metric_WideTerminal_Tight

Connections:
ACCELL_INT1: S1J2.16, S8U1.4 (INT1)
ACCELL_INT2: S1J2.17, S8U1.9 (INT2)
CAN_CS: S1J3.23 (Pin_18), S9R1.2, S9R5.1
CAN_ENABLE: S1J3.31 (Pin_10), S1R4.2, S7U2.3 (ON)
CAN_H: S5R1.2, S9D1.1 (K), S9FL1.2, S9R3.2
CAN_H_KWIRE_K: S1J1.3, S5R1.1, S5R2.1
CAN_INT: S1J3.27 (Pin_14), S9R2.2, S9U2.4 (~INT)
CAN_L: S5R3.2, S9D1.2 (K), S9FL1.3, S9J1.2
CAN_L_KWIRE_L: S1J1.6, S5R3.1, S5R4.1
CAN_SCK: S1J3.25 (Pin_16), S9R6.1
CAN_SDI: S1J3.24 (Pin_17), S9R7.1
CAN_SDO: S1J3.26 (Pin_15), S9U2.12 (SDO)
GND: S1C1.1, S1J1.2, S1J2.3 (GND), S1J3.39 (Pin_2), S1J4.2, S1R3.1, S1R4.1, S1R5.1, S2C1.2, S2C2.2, S2C3.2, S2D2.2 (A), S2D4.2 (A), S2R1.2, S2R2.2, S3C1.1, S3C2.1, S3U1.1 (A1), S3U1.2 (A0), S3U1.7 (GND), S4C1.2, S4Q1.2 (S), S4R2.1, S6C2.2, S6C3.2, S6C5.2, S6C8.2, S6R1.2, S6R2.2, S6R5.1, S6U1.5 (SYNC), S6U1.11 (GND), S7C1.2, S7C2.2, S7C3.2, S7C4.2, S7C5.2, S7C6.2, S7C7.2, S7C8.2, S7C9.2, S7Q1.2 (S), S7R2.1, S7R4.1, S7R6.1, S7R9.1, S7U1.2 (GND), S7U1.5 (GND), S7U2.2 (GND), S7U2.5 (GND), S7U3.1 (GND), S7U4.2 (GND), S7U4.5 (GND), S8C1.2, S8C2.2, S8C3.2, S8C4.2, S8C5.2, S8U1.1 (SDO/SA0), S8U1.2 (MSDA), S8U1.3 (MSCL), S8U1.6 (NC), S8U1.7 (GND), S9C1.2, S9C2.2, S9C3.2, S9C4.2, S9C5.2, S9D1.3 (A), S9R4.2, S9U1.2 (GND), S9U1.5 (SHDN), S9U2.7 (VSS), S9Y1.2 (GND_1), S9Y1.4 (GND_2), S10C1.1, S10D2.2 (A), S10D4.2 (A), S10Q1.2 (S), S10R5.2, S10R6.1, S10R9.1, S10U1.5 (GND), S11C1.2, S11C2.2, S11C3.1, S11R2.1, S11R6.1, S11U1.2 (GND), S11U1.5 (ST), S11U2.3 (ANODE), S12TP1.1 (1_1), S13D1.1 (K), S13D2.1 (K), S13D3.1 (K), S15C2.2, S15C3.2, S15C4.2, S15D1.2 (GND), S15D2.2 (GND), S15J1.2 (Ext), S15J2.2, S15J2.3, S15J2.4, S15J2.5, S15J3.2 (Ext), S15J4.2, S15J4.3, S15J4.4, S15J4.5
GPS_ENABLE: S1J3.21 (Pin_20), S1R3.2, S7U1.3 (ON)
I2C_SCL: S1J3.29 (Pin_12), S1R2.1, S3U1.5 (SCL), S8C5.1, S8U1.13 (SCL)
I2C_SDA: S1J3.28 (Pin_13), S1R1.1, S3U1.4 (SDA), S8C4.1, S8U1.14 (SDA)
IGN_SENSE: S1J3.32 (Pin_9), S4Q1.3 (D), S4R3.2
ISO9141_K: S5R2.2, S10D2.1 (K), S10R3.2, S10U1.6 (LIN)
ISO9141_L: S5R4.2, S10D4.1 (K), S10R4.2, S10U2.1 (IN)
K_ENABLE: S1J3.33 (Pin_8), S1R5.2, S7U3.2 (IN), S7U4.3 (ON)
K_RX: S1J2.11, S10R1.2, S10U1.1 (RXD)
K_SLEEP: S1J2.12, S10R6.2, S10U1.2 (SLP_N)
K_TX: S1J2.13, S10R2.2, S10U1.4 (TXD)
LED1: S1J2.18, S13R1.2
LED2: S1J2.19, S13R2.2
LED3: S1J2.20, S13R3.2
L_SEND: S1J2.10, S10R5.1, S10R7.1
L_SENSE: S1J3.22 (Pin_19), S10R8.1
unnamed: S2D1.1 (A), S2Q1.1 (G), S2R1.1
unnamed: S2D2.1 (K), S2F1.1, S2Q1.3 (D)
unnamed: S2D3.1 (A), S2Q2.4, S2R2.1
unnamed: S2D4.1 (K), S2F2.2, S2Q2.5_0, S2Q2.5_1, S2Q2.5_2, S2Q2.5_3
unnamed: S4C1.1, S4Q1.1 (G), S4R1.2, S4R2.2
unnamed: S6C1.1, S6U1.1 (BST)
unnamed: S6R4.1, S6R5.2, S6R6.2, S6U1.10 (EN/UV)
unnamed: S6C4.1, S6R2.1, S6R3.1, S6U1.6 (FB)
unnamed: S6C2.1, S6U1.3 (INTVCC)
unnamed: S6R1.1, S6U1.4 (RT)
unnamed: S6C1.2, S6L1.1, S6U1.2 (SW)
unnamed: S7Q1.1 (G), S7R5.2, S7R6.2
unnamed: S8C1.1, S8C2.1, S8C3.1, S8R1.2, S8U1.5 (VDD_IO), S8U1.8 (VDD), S8U1.12 (CS)
unnamed: S9J1.1, S9R3.1
unnamed: S9FL1.1, S9U1.7 (CANH)
unnamed: S9FL1.4, S9U1.6 (CANL)
unnamed: S9U1.4 (RXD), S9U2.2 (RXCAN)
unnamed: S9R4.1, S9U1.8 (STBY), S9U2.9 (~INT0/GPIO0/XSTBY)
unnamed: S9U1.1 (TXD), S9U2.1 (TXCAN)
unnamed: S9C3.1, S9U2.6 (OSC1), S9Y1.1 (IN/OUT)
unnamed: S9C2.1, S9U2.5 (OSC2), S9Y1.3 (OUT/IN)
unnamed: S9R6.2, S9U2.10 (SCK)
unnamed: S9R7.2, S9U2.11 (SDI)
unnamed: S9R5.2, S9U2.13 (~CS)
unnamed: S10D1.1 (K), S10R3.1
unnamed: S10D3.1 (K), S10R4.1
unnamed: S10D5.2 (A), S10R8.2
unnamed: S10D5.1 (K), S10Q1.3 (D), S10U2.2 (OUT)
unnamed: S10Q1.1 (G), S10R7.2, S10R9.2
unnamed: S11D1.1 (A), S11Q1.1 (G), S11Q2.3, S11R2.2, S11R3.2
unnamed: S11Q2.1, S11R1.1, S11R4.2
unnamed: S11R4.1, S11U2.1 (CATHODE)
unnamed: S11C3.2, S11R3.1, S11R5.2, S11R6.2, S11U2.2 (REF)
unnamed: S13D1.2 (A), S13R1.1
unnamed: S13D2.2 (A), S13R2.1
unnamed: S13D3.2 (A), S13R3.1
unnamed: S15C2.1, S15C3.1, S15C4.1, S15FB1.2, S15L1.1
unnamed: S15D1.1 (I/O), S15J3.1 (In), S15J4.1
unnamed: S15FB1.1, S15R1.1
unnamed: S15C1.1, S15J1.1 (In)
PP3V3: S1J3.40 (Pin_1), S1R1.2, S1R2.2, S3C1.2, S3C2.2, S3U1.6 (VS), S4R3.1, S7C1.1, S7C3.1, S7C8.1, S7R7.2, S7U1.4 (IN), S7U2.4 (IN), S7U4.4 (IN), S8R1.1, S12TP3.1 (1_1)
PP3V3_CAN: S7C4.1, S7R3.1, S7U2.1 (OUT), S9C1.1, S9C4.1, S9C5.1, S9R1.1, S9R2.1, S9U1.3 (VDD), S9U2.14 (VDD), S12TP5.1 (1_1)
PP3V3_CAN_ST: S1J3.30 (Pin_11), S7R3.2, S7R4.2
PP3V3_GPS: S7C2.1, S7R1.1, S7U1.1 (OUT), S12TP4.1 (1_1), S15R1.2
PP3V3_GPS_ST: S1J2.9, S7R1.2, S7R2.2
PP3V3_K: S7C9.1, S7R8.1, S7U4.1 (OUT), S10R1.1, S10R2.1, S12TP6.1 (1_1)
PP3V3_K_ST: S1J2.14, S7R8.2, S7R9.2
PP4V2: S1C1.2, S1J4.1, S11C1.1, S11C2.1, S11U1.3 (~CE), S11U1.6 (VOUT), S12TP2.1 (1_1)
PP4V2_OVP_PROTECTED: S5R5.2, S11Q1.3 (D), S11U1.1 (VIN)
PP4V2_UNPROTECTED: S5R5.1, S6C4.2, S6C5.1, S6L1.2, S6R3.2, S6R6.1, S11D1.3 (K), S11Q1.2 (S), S11Q2.2, S11R1.2, S11R5.1
PP12V: S1J1.4, S2F2.1
PP12VI: S1J1.5, S2F1.2
PP12VIP: S2D1.3 (K), S2Q1.2 (S), S4R1.1
PP12VP: S2C1.1, S2C2.1, S2C3.1, S2D3.3 (K), S2Q2.1, S2Q2.2, S2Q2.3, S3U1.8 (Vbus), S3U1.9 (Vin-), S3U1.10 (Vin+), S6C3.1, S6C8.1, S6R4.2, S6U1.9 (VIN), S7C6.1, S7U3.5 (VS_1), S7U3.6 (VS_2), S7U3.7 (VS_3), S7U3.8 (VS_4)
PP12V_K: S7C5.1, S7R5.1, S7U3.3 (OUT), S10C1.2, S10D1.2 (A), S10D3.2 (A), S10U1.7 (VBAT), S12TP7.1 (1_1)
PP12V_K_ST: S1J2.15, S7C7.1, S7Q1.3 (D), S7R7.1
RF: S15C1.2, S15D2.1 (I/O), S15J2.1, S15L1.2

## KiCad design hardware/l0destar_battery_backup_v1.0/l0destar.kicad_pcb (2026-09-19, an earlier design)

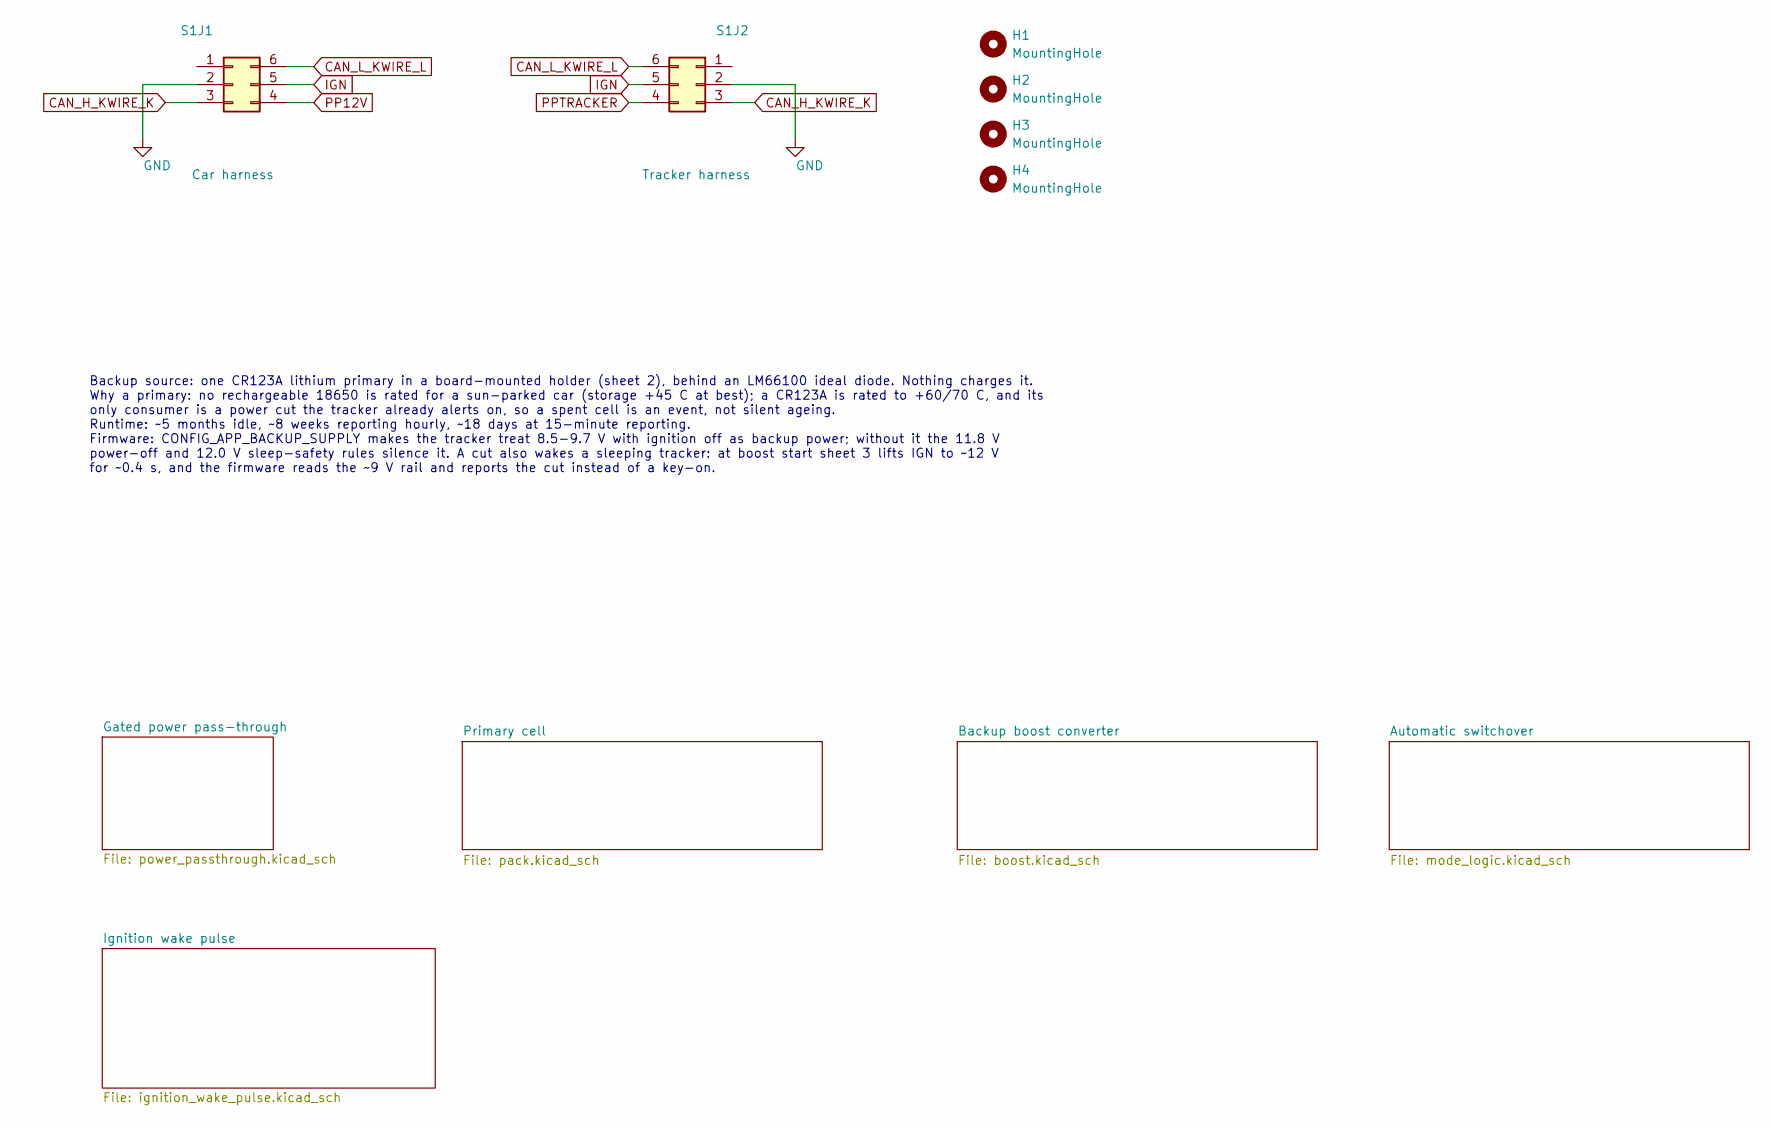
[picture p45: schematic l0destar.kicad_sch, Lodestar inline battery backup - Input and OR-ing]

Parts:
H1, H2, H3, H4: MountingHole; MountingHole_2.2mm_M2
S1J1: Car harness; Molex_Micro-Fit_3.0_43045-0600_2x03_P3.00mm_Horizontal
S1J2: Tracker harness; Molex_Micro-Fit_3.0_43045-0600_2x03_P3.00mm_Horizontal

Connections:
CAN_H_KWIRE_K: S1J1.3, S1J2.3
CAN_L_KWIRE_L: S1J1.6, S1J2.6
GND: S1J1.2, S1J2.2; also elsewhere on the board
IGN: S1J1.5, S1J2.5; also elsewhere on the board
PP12V: S1J1.4; also elsewhere on the board
PPTRACKER: S1J2.4; also elsewhere on the board

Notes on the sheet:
Backup source: one CR123A lithium primary in a board-mounted holder (sheet 2), behind an LM66100 ideal diode. Nothing charges it. Why a primary: no rechargeable 18650 is rated for a sun-parked car (storage +45 C at best); a CR123A is rated to +60/70 C, and its only consumer is a power cut the track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


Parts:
S3BT1: CR123A; 1051_KEY; MPN 1051
S3C1: 0603 2.2uF 25V 10% X7R; C_0603_1608Metric; MPN GRM188Z71E225KE43D
S3F1: 0407002.WRA; Fuse_1206_3216Metric; MPN 0407002.WRA
S3U1: LM66100DCKR; SOT-363_SC-70-6; MPN LM66100DCKR

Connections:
GND: S3BT1.2, S3C1.2, S3U1.2 (GND), S3U1.3 (~CE); also elsewhere on the board
unnamed: S3BT1.1, S3F1.1
unnamed: S3C1.1, S3F1.2, S3U1.1 (VIN)
VBAT: S3U1.6 (VOUT); also elsewhere on the board

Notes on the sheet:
PRIMARY CELL - NOT RECHARGEABLE
CR123 primary cell. Ideal diode prevents any fault charging the cell and makes a reversed cell harmless.

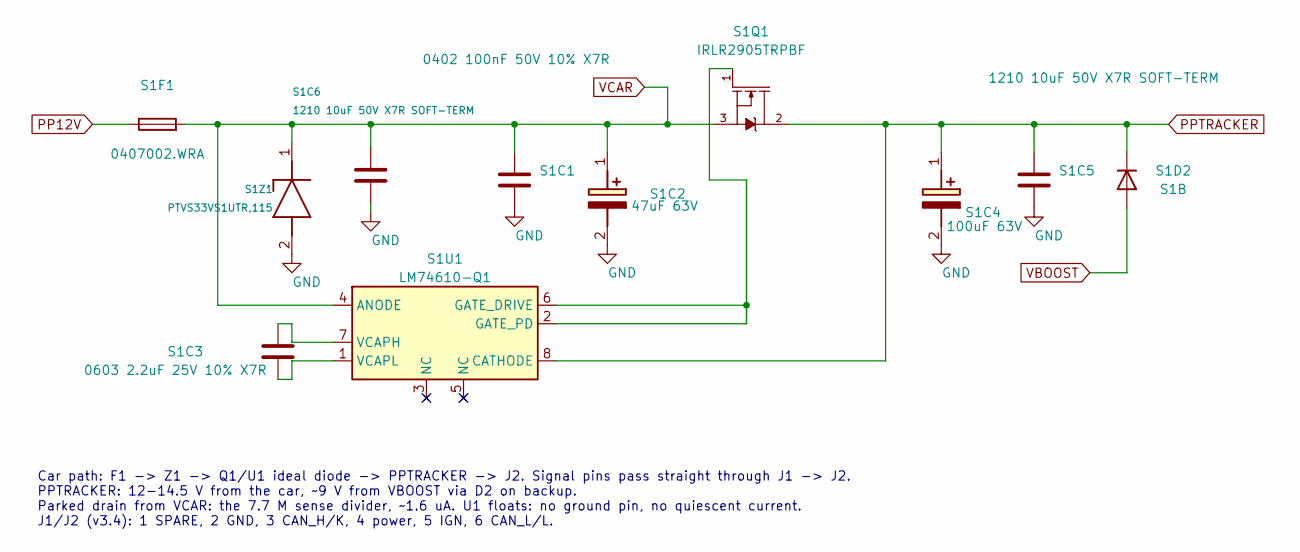
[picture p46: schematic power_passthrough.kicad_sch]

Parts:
S1C1: 0402 100nF 50V 10% X7R; C_0402_1005Metric; MPN GRM155R71H104KE14D
S1C2: 47uF 63V; EEE_FK1J470P; MPN EEE-FK1J470P
S1C3: 0603 2.2uF 25V 10% X7R; C_0603_1608Metric; MPN GRM188Z71E225KE43D
S1C4: 100uF 63V; EEEFK1J101P; MPN EEE-FK1J101P
S1C5, S1C6: 1210 10uF 50V X7R SOFT-TERM; C_1210_3225Metric; MPN MCJCU32MLB7106KPPDT1
S1D2: S1B; D_SMA; MPN S1B
S1F1: 0407002.WRA; Fuse_1206_3216Metric; MPN 0407002.WRA
S1Q1: IRLR2905TRPBF
S1U1: LM74610-Q1; VSSOP-8_3x3mm_P0.65mm; MPN LM74610QDGKRQ1
S1Z1: PTVS33VS1UTR,115; Nexperia_CFP3_SOD-123W; MPN PTVS33VS1UTR,115

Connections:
GND: S1C1.2, S1C2.2 (-), S1C4.2 (-), S1C5.2, S1C6.2, S1Z1.2 (A); also elsewhere on the board
unnamed: S1Q1.1, S1U1.2 (GATE_PD), S1U1.6 (GATE_DRIVE)
unnamed: S1C3.1, S1U1.7 (VCAPH)
unnamed: S1C3.2, S1U1.1 (VCAPL)
PP12V: S1F1.1; also elsewhere on the board
PPTRACKER: S1C4.1 (+), S1C5.1, S1D2.1 (K), S1Q1.2, S1Q1.PAD, S1U1.8 (CATHODE); also elsewhere on the board
VBOOST: S1D2.2 (A); also elsewhere on the board
VCAR: S1C1.1, S1C2.1 (+), S1C6.1, S1F1.2, S1Q1.3, S1U1.4 (ANODE), S1Z1.1 (K); also elsewhere on the board

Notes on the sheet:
Car path: F1 -> Z1 -> Q1/U1 ideal diode -> PPTRACKER -> J2. Signal pins pass straight through J1 -> J2. PPTRACKER: 12-14.5 V from the car, ~9 V from VBOOST via D2 on backup. Parked drain from VCAR: the 7.7 M sense divider, ~1.6 uA. U1 floats: no ground pin, no quiescent current. J1/J2 (v3.4): 1 SPA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

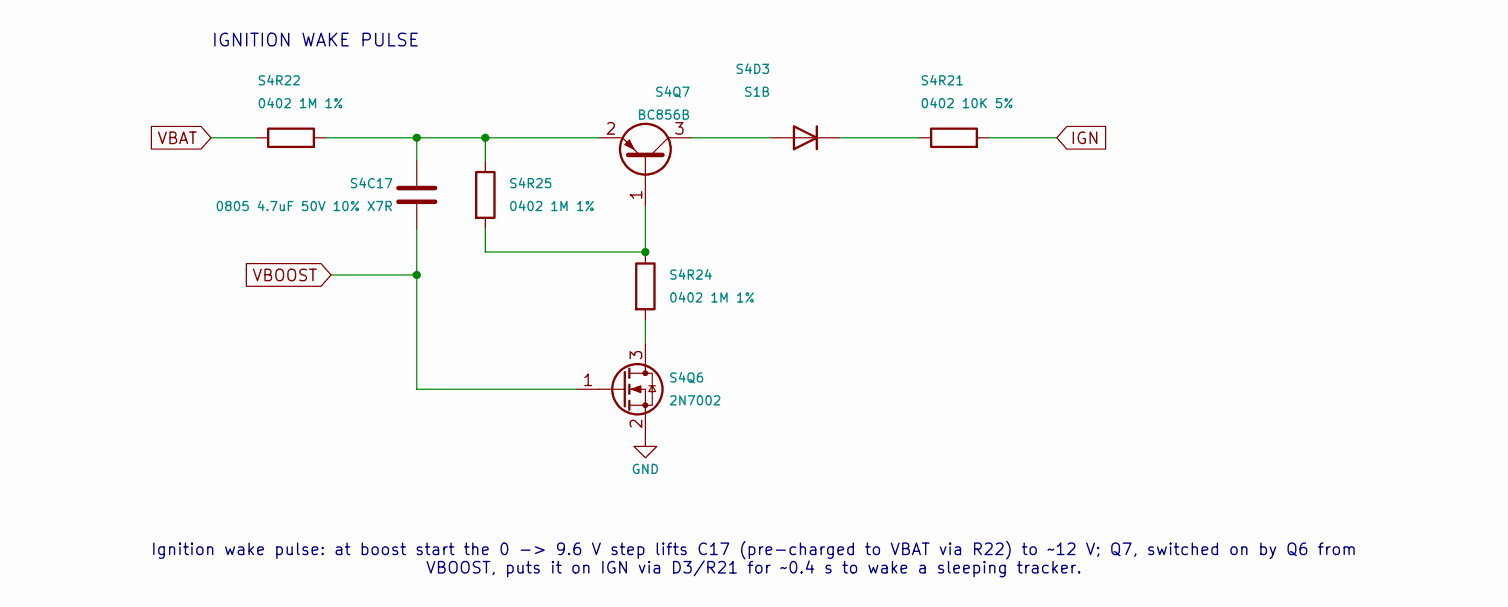
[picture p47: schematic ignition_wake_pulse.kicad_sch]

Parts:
S4C17: 0805 4.7uF 50V 10% X7R; C_0805_2012Metric; MPN GRM21BZ71H475KE15K
S4D3: S1B; D_SMA; MPN S1B
S4Q6: 2N7002; SOT-23; MPN 2N7002
S4Q7: BC856B; SOT-23; MPN BC856B
S4R21: 0402 10K 5%; R_0402_1005Metric
S4R22, S4R24, S4R25: 0402 1M 1%; R_0402_1005Metric

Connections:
GND: S4Q6.2 (S); also elsewhere on the board
IGN: S4R21.2; also elsewhere on the board
unnamed: S4D3.2 (A), S4Q7.3 (C)
unnamed: S4D3.1 (K), S4R21.1
unnamed: S4Q6.3 (D), S4R24.2
unnamed: S4Q7.1 (B), S4R24.1, S4R25.2
unnamed: S4C17.1, S4Q7.2 (E), S4R22.2, S4R25.1
VBAT: S4R22.1; also elsewhere on the board
VBOOST: S4C17.2, S4Q6.1 (G); also elsewhere on the board

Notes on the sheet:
IGNITION WAKE PULSE
Ignition wake pulse: at boost start the 0 -> 9.6 V step lifts C17 (pre-charged to VBAT via R22) to ~12 V; Q7, switched on by Q6 from VBOOST, puts it on IGN via D3/R21 for ~0.4 s to wake a sleeping tracker.

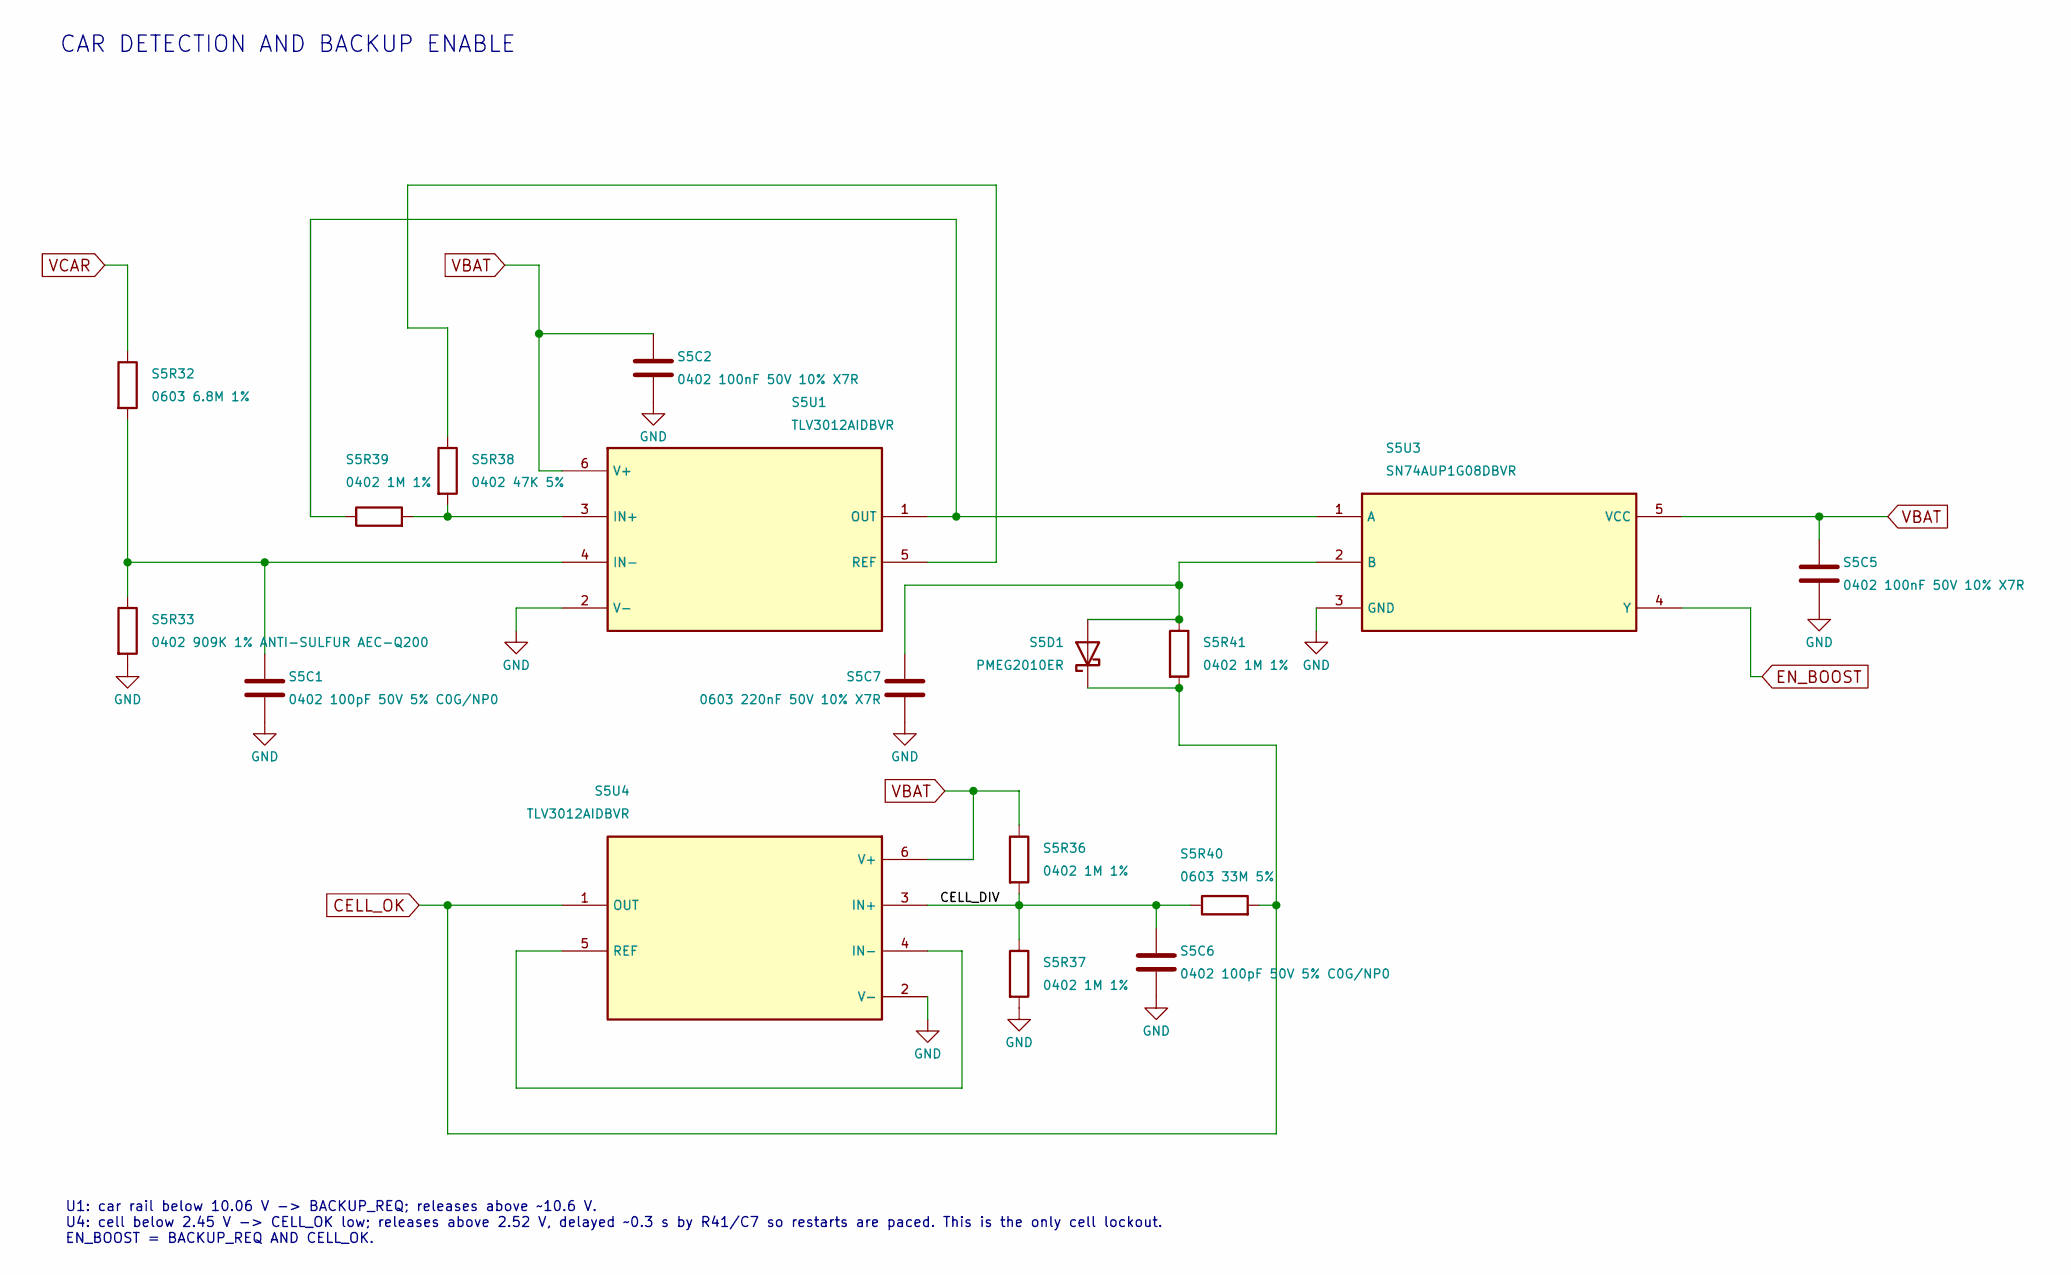
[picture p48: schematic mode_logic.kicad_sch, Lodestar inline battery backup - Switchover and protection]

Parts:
S5C1, S5C6: 0402 100pF 50V 5% C0G/NP0; C_0402_1005Metric; MPN 0402N101J500CT
S5C2, S5C5: 0402 100nF 50V 10% X7R; C_0402_1005Metric; MPN GRM155R71H104KE14D
S5C7: 0603 220nF 50V 10% X7R; C_0603_1608Metric
S5D1: PMEG2010ER; Nexperia_CFP3_SOD-123W; MPN PMEG2010ER,115
S5R32: 0603 6.8M 1%; R_0603_1608Metric
S5R33: 0402 909K 1% ANTI-SULFUR AEC-Q200; R_0402_1005Metric; MPN AF0402FR-07909KL
S5R36, S5R37, S5R39, S5R41: 0402 1M 1%; R_0402_1005Metric
S5R38: 0402 47K 5%; R_0402_1005Metric
S5R40: 0603 33M 5%; R_0603_1608Metric
S5U1, S5U4: TLV3012AIDBVR; SOT-23-6; MPN TLV3012AIDBVR
S5U3: SN74AUP1G08DBVR; SOT-23-5; MPN SN74AUP1G08DBVR

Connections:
/Automatic switchover/CELL_DIV: S5C6.1, S5R36.2, S5R37.1, S5R40.1, S5U4.3 (IN+)
CELL_OK: S5D1.1 (K), S5R40.2, S5R41.2, S5U4.1 (OUT)
EN_BOOST: S5U3.4 (Y); also elsewhere on the board
GND: S5C1.2, S5C2.2, S5C5.2, S5C6.2, S5C7.2, S5R33.2, S5R37.2, S5U1.2 (V-), S5U3.3 (GND), S5U4.2 (V-); also elsewhere on the board
unnamed: S5C7.1, S5D1.2 (A), S5R41.1, S5U3.2 (B)
unnamed: S5R38.2, S5R39.2, S5U1.3 (IN+)
unnamed: S5C1.1, S5R32.2, S5R33.1, S5U1.4 (IN-)
unnamed: S5R39.1, S5U1.1 (OUT), S5U3.1 (A)
unnamed: S5R38.1, S5U1.5 (REF)
unnamed: S5U4.4 (IN-), S5U4.5 (REF)
VBAT: S5C2.1, S5C5.1, S5R36.1, S5U1.6 (V+), S5U3.5 (VCC), S5U4.6 (V+); also elsewhere on the board
VCAR: S5R32.1; also elsewhere on the board

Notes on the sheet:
CAR DETECTION AND BACKUP ENABLE
U1: car rail below 10.06 V -> BACKUP_REQ; releases above ~10.6 V. U4: cell below 2.45 V -> CELL_OK low; releases above 2.52 V, delayed ~0.3 s by R41/C7 so restarts are paced. This is the only cell lockout. EN_BOOST = BACKUP_REQ AND CELL_OK.


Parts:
S4C7, S4C8: 1210 47uF 10V 20% X7R; C_1210_3225Metric; MPN CL32B476MPJNNNE
S4C9: 0402 100nF 50V 10% X7R; C_0402_1005Metric; MPN GRM155R71H104KE14D
S4C11: 0402 560pF 50V 5% C0G/NP0; C_0402_1005Metric
S4C12: 0402 10pF 50V C0G/NP0; C_0402_1005Metric; MPN GRM1555C1H100JA01D
S4C13: 0805 4.7uF 50V 10% X7R; C_0805_2012Metric; MPN GRM21BZ71H475KE15K
S4C14, S4C15: 1210 10uF 50V X7R SOFT-TERM; C_1210_3225Metric; MPN MCJCU32MLB7106KPPDT1
S4L1: 2.2uH XFL4020-222MEC; IND_XFL4020-222ME; MPN XFL4020-222MEC
S4R14: 0402 57.6K 1%; R_0402_1005Metric
S4R18: 0402 200K 1%; R_0402_1005Metric
S4R19: 0402 909K 1% ANTI-SULFUR AEC-Q200; R_0402_1005Metric; MPN AF0402FR-07909KL
S4R20: 0402 130K 1%; R_0402_1005Metric
S4U5: LTC3122EMSE#PBF; MSOP-12-1EP_3x4.039mm_P0.65mm_EP1.651x2.845mm; MPN LTC3122EMSE#PBF

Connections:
EN_BOOST: S4U5.9 (SD); also elsewhere on the board
GND: S4C7.2, S4C8.2, S4C11.2, S4C12.2, S4C13.2, S4C14.2, S4C15.2, S4R14.2, S4R20.2, S4U5.2 (PGND), S4U5.4 (PWM/SYNC), S4U5.10 (SGND), S4U5.13 (EP); also elsewhere on the board
unnamed: S4C11.1, S4R18.2
unnamed: S4C9.1, S4U5.12 (CAP)
unnamed: S4R19.2, S4R20.1, S4U5.8 (FB)
unnamed: S4R14.1, S4U5.6 (RT)
unnamed: S4L1.2, S4U5.1 (SW)
unnamed: S4C12.1, S4R18.1, S4U5.7 (VC)
unnamed: S4C13.1, S4U5.5 (VCC)
VBAT: S4C7.1, S4C8.1, S4L1.1, S4U5.3 (VIN); also elsewhere on the board
VBOOST: S4C9.2, S4C14.1, S4C15.1, S4R19.1, S4U5.11 (VOUT); also elsewhere on the board

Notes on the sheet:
LTC3122 boost, Burst Mode (PWM/SYNC low), true output disconnect: VBOOST is 0 V while the car is present. 9.6 V here, ~9 V at the tracker. Burst Mode output is ~190 mA at 2.5 V in, ~300 mA at 3 V; LTE bursts ride on C14/C15 and the tracker's own input capacitance. No usable input UVLO (runs to 0.5 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
POWER STAGE / BURST MODE


Board: 4 copper layers, 63.1 x 36.2 mm, 60 parts (0 on the bottom side), 35 nets.

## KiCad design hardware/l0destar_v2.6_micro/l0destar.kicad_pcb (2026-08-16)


Board: 4 copper layers, 66.8 x 34.4 mm, 74 parts (0 on the bottom side), 38 nets.

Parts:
GND1: TestPoint; TestPoint_Pad_1.0x1.0mm
H1, H2, H3, H4: MountingHole; MountingHole_2.2mm_M2
PP3V3, PP3V3AUX1, PP3V3GPS2, PP4V5, PP12VIP1, PP12VP1: TestPoint; TestPoint_Pad_1.0x1.0mm
S1C1, S1C2: 220uF; C_1210_3225Metric
S1J1: Main connector; Molex_Micro-Fit_3.0_43045-0400_2x02_P3.00mm_Horizontal
S1J2: Conn_01x20_Socket; MakerDiary_nRF9151_ConnectKit_PinHeader_1-20
S1J3: Conn_01x20_Socket_21-40; MakerDiary_nRF9151_ConnectKit_PinHeader_21-40
S1J4: VCC; PinSocket_1x02_P2.54mm_Vertical
S1R1, S1R2: 4.7K; R_0402_1005Metric
S2C1: CKG57NX7R1H476M500JH 47uF; CAPC6050X550N
S2D1, S2D3: BZX84C15; SOT-23
S2D2, S2D4: PTVS33VS1UTR,115; Nexperia_CFP3_SOD-123W
S2Q1, S2Q2: SQ2361; SOT-23
S2R1, S2R2, S6R3, S7R2: 1M; R_0402_1005Metric
S3C1, S6C2, S15C4: 1uF; C_0402_1005Metric
S3C2, S4C1, S6C1, S8C1, S8C3: 100nF; C_0402_1005Metric
S3U1: INA228; TSSOP-10_3x3mm_P0.5mm
S4Q1, S7Q1: 2N7002; SOT-23
S4R1: 120K; R_0402_1005Metric
S4R2: 47K; R_0402_1005Metric
S4R3: 56K; R_0402_1005Metric
S6C3: 4.7uF; C_0805_2012Metric
S6C4: 10pF; C_0402_1005Metric
S6C5: 22uF; C_0805_2012Metric
S6L1: XFL4020-222ME; IND_XFL4020-222ME
S6R1: 18.2K; R_0402_1005Metric
S6R2: 226K; R_0402_1005Metric
S6U1: LT8609AIMSE_PBF; LT8609AIMSE_WITH_GROUND_VIAS
S6U2, S15U1: LM66100DCK; SOT-363_SC-70-6
S7Q2: DMG3415U; SOT-23
S7R1, S7R3: 100K; R_0402_1005Metric
S7R4: 470K; R_0402_1005Metric
S8C2: 10uF; C_0603_1608Metric
S8U1: ASM330LHHXTR; XDCR_ASM330LHHXTR
S13D1, S13D2, S13D3: LED; LED_0603_1608Metric
S13R1, S13R2, S13R3: 1K; R_0402_1005Metric
S15C1, S15C2: 100pF; C_0402_1005Metric
S15C3: 10nF; C_0402_1005Metric
S15FB1: 600R; L_0402_1005Metric
S15J1: GPS_UFL; U.FL_Hirose_U.FL-R-SMT-1_Vertical
S15J2: GPS_SMA; SAMTEC_SMA-J-P-H-RA-TH1
S15J3: GSM_UFL; U.FL_Hirose_U.FL-R-SMT-1_Vertical
S15J4: GSM_SMA; SAMTEC_SMA-J-P-H-RA-TH1
S15L1: 47-100 nH, SRF > 2 GHz; L_0603_1608Metric

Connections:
ACCELL_INT1: S1J2.15, S8U1.4 (INT1)
ACCELL_INT2: S1J2.17, S8U1.9 (INT2)
AUX_ENABLE: S1J3.32 (Pin_9), S7R1.1
GND: GND1.1 (1_1), S1C1.2, S1C2.2, S1J1.1, S1J2.3 (GND), S1J3.39 (Pin_2), S1J4.2, S2C1.2, S2D2.2 (A), S2D4.2 (A), S2R1.2, S2R2.2, S3C1.1, S3C2.1, S3U1.1 (A1), S3U1.2 (A0), S3U1.7 (GND), S4C1.2, S4Q1.2 (S), S4R2.1, S6C2.2, S6C3.2, S6C5.2, S6R1.2, S6R2.2, S6U1.5 (SYNC), S6U1.11 (GND), S6U2.2 (GND), S6U2.5 (ST), S7Q1.2 (S), S7R2.1, S8C1.2, S8C2.2, S8C3.2, S8U1.1 (SDO/SA0), S8U1.2 (MSDA), S8U1.3 (MSCL), S8U1.6 (NC), S8U1.7 (GND), S8U1.10 (NC), S8U1.11 (NC), S13D1.1 (K), S13D2.1 (K), S13D3.1 (K), S15C2.2, S15C3.2, S15C4.2, S15J1.2 (Ext), S15J2.2, S15J2.3, S15J2.4, S15J2.5, S15J3.2 (Ext), S15J4.2, S15J4.3, S15J4.4, S15J4.5, S15U1.2 (GND), S15U1.5 (ST)
I2C_SCL: S1J3.27 (Pin_14), S1R2.1, S3U1.5 (SCL), S8U1.13 (SCL)
I2C_SDA: S1J3.28 (Pin_13), S1R1.1, S3U1.4 (SDA), S8U1.14 (SDA)
IGN_SENSE: S1J3.33 (Pin_8), S4Q1.3 (D), S4R3.2
INA_ALRT: S1J3.29 (Pin_12), S3U1.3 (~Alert)
LED1: S1J2.20, S13R1.2
LED2: S1J2.19, S13R2.2
LED3: S1J2.18, S13R3.2
unnamed: S2D1.1 (A), S2Q1.1 (G), S2R1.1
unnamed: S2D3.1 (A), S2Q2.1 (G), S2R2.1
unnamed: S4C1.1, S4Q1.1 (G), S4R1.2, S4R2.2
unnamed: S6C1.1, S6U1.1 (BST)
unnamed: S6C4.1, S6R2.1, S6R3.1, S6U1.6 (FB)
unnamed: S6C2.1, S6U1.3 (INTVCC)
unnamed: S6R1.1, S6U1.4 (RT)
unnamed: S6C1.2, S6L1.1, S6U1.2 (SW)
unnamed: S6C4.2, S6C5.1, S6L1.2, S6R3.2, S6U2.1 (VIN)
unnamed: S7Q1.3 (D), S7R3.2
unnamed: S7Q1.1 (G), S7R1.2, S7R2.2
unnamed: S7Q2.1 (G), S7R3.1, S7R4.2
unnamed: S13D1.2 (A), S13R1.1
unnamed: S13D2.2 (A), S13R2.1
unnamed: S13D3.2 (A), S13R3.1
unnamed: S15C2.1, S15C3.1, S15C4.1, S15FB1.2, S15L1.1
unnamed: S15C1.1, S15J1.1 (In)
unnamed: S15J3.1 (In), S15J4.1
PP3V3: PP3V3.1 (1_1), S1J3.40 (Pin_1), S1R1.2, S1R2.2, S3C1.2, S3C2.2, S3U1.6 (VS), S4R3.1, S7Q2.2 (S), S7R4.1, S8C1.1, S8C2.1, S8C3.1, S8U1.5 (VDD_IO), S8U1.8 (VDD), S8U1.12 (CS)
PP3V3_AUX: PP3V3AUX1.1 (1_1), S7Q2.3 (D), S15U1.1 (VIN)
PP3V3_GPS: PP3V3GPS2.1 (1_1), S15FB1.1, S15U1.3 (~CE), S15U1.6 (VOUT)
PP4V2: PP4V5.1 (1_1), S1C1.1, S1C2.1, S1J4.1, S6U2.3 (~CE), S6U2.6 (VOUT)
PP12V: S1J1.3, S2D4.1 (K), S2Q2.3 (D)
PP12VI: S1J1.4, S2D2.1 (K), S2Q1.3 (D)
PP12VIP: PP12VIP1.1 (1_1), S2D1.3 (K), S2Q1.2 (S), S4R1.1
PP12VP: PP12VP1.1 (1_1), S2C1.1, S2D3.3 (K), S2Q2.2 (S), S3U1.8 (Vbus), S3U1.9 (Vin-), S3U1.10 (Vin+), S6C3.1, S6U1.9 (VIN), S6U1.10 (EN/UV)
RF: S15C1.2, S15J2.1, S15L1.2

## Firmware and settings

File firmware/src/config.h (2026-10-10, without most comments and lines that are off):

#define APP_CONFIG_H_
#define HOSTNAME            ""
#define UDP_PORT            CONFIG_APP_SERVER_PORT
#define TLS_PORT            65481
#define DTLS_PORT           5684
#define UDP_PACKET_SIZE     1200
#define RESPONSE_TIMEOUT_MS 4000
#define TLS_SEC_TAG         1
#define PSK_HEX_DEFAULT \
    "0000000000000000000000000000000000000000000000000000000000000000"
#define DEFAULT_APN         "sensor.net"
#define DEFAULT_USER        ""
#define DEFAULT_PASS        ""
#define ENGINE_OFF_LOOP_INTERVAL    CONFIG_APP_ENGINE_OFF_LOOP_INTERVAL
#define ENGINE_OFF_BOOT_INTERVAL    3600
#define IGNITION_ON_SLEEP_INTERVAL  CONFIG_APP_IGNITION_ON_SLEEP_INTERVAL
#define VOLTAGE_POLL_INTERVAL       CONFIG_APP_VOLTAGE_POLL_INTERVAL
#define BATTERY_CHECK_INTERVAL      CONFIG_APP_BATTERY_CHECK_INTERVAL
#define NETWORK_REGISTRATION_TIMEOUT CONFIG_APP_NETWORK_REGISTRATION_TIMEOUT
#define NETWORK_RETRY_INTERVAL      CONFIG_APP_NETWORK_RETRY_INTERVAL
#define NETWORK_SEARCH_TIMEOUT      CONFIG_APP_NETWORK_SEARCH_TIMEOUT
#define NO_SIGNAL_MAX_INTERVAL      CONFIG_APP_NO_SIGNAL_MAX_INTERVAL
#define RESEND_POLL_S               30
#define GPS_FIX_TIMEOUT_MS          CONFIG_APP_GPS_FIX_TIMEOUT_MS
#define GPS_COLD_FIX_TIMEOUT_MS     CONFIG_APP_GPS_COLD_FIX_TIMEOUT_MS
#define TRANSITION_FIX_WAIT_MS      15000
#define AGNSS_RETRIES               2
#define AGNSS_RETRY_INTERVAL_MS     15000
#define AGNSS_FIX_FRESH_MS          (30 * 60 * 1000)
#define SIGNAL_FRESH_MS             60000
#define SIGNAL_SAMPLE_MS            ((int64_t)CONFIG_APP_SIGNAL_SAMPLE_S * 1000)
#define GNSS_PRIO_STARVED_EPOCHS    5
#define GNSS_PRIO_WINDOW_MS         40000
#define BATTERY_WARNING_LEVEL       (CONFIG_APP_BATTERY_WARNING_MV / 1000.0f)
#define BATTERY_POWEROFF_LEVEL      (CONFIG_APP_BATTERY_POWEROFF_MV / 1000.0f)
#define SLEEP_SAFETY_VOLTAGE        (CONFIG_APP_SLEEP_SAFETY_MV / 1000.0f)
#define ENGINE_RUNNING_VOLTAGE      (CONFIG_APP_ENGINE_RUNNING_MV / 1000.0f)
#define IMPLAUSIBLE_VOLTAGE         5.0f
#ifdef CONFIG_APP_BACKUP_SUPPLY
#define BACKUP_SUPPLY_MIN           (CONFIG_APP_BACKUP_MIN_MV / 1000.0f)
#define BACKUP_SUPPLY_MAX           (CONFIG_APP_BACKUP_MAX_MV / 1000.0f)
#else
#define BACKUP_SUPPLY_MIN           0.0f
#define BACKUP_SUPPLY_MAX           0.0f
#endif
#define IGN_WAKE_DEBOUNCE_MS        200
#define IGN_OFF_CONFIRM_MS          50
#define IGN_CRANK_MAX_MS            5000
#define BACKUP_PULSE_MAX_MS         1500
#define BACKUP_SETTLE_MS            60000
#define BACKUP_CONFIRM_MS           2000
#define BACKUP_FALL_MIN_V           0.02f
#define BACKUP_POLL_MS              250
#define BACKUP_RAIL_POLL_S          30
#define ENGINE_STOPPED_HOLD_S       300
#define ENGINE_MOVING_KMH           3.0f
#define ENGINE_FIX_MAX_AGE_S        180
#define BATTERY_WARN_SETTLE_S       60
#define BATTERY_SAMPLES             8
#define BATTERY_SAMPLE_GAP_MS       3
#define BATTERY_SPREAD_WARN_V       0.5f
#define ACC_MOVEMENT_THRESHOLD      CONFIG_APP_ACC_MOVEMENT_THRESHOLD
#define MOVEMENT_INACTIVITY_RESET   CONFIG_APP_MOVEMENT_INACTIVITY_RESET
#define CRASH_THRESHOLD_MG          CONFIG_APP_CRASH_THRESHOLD_MG
#define PARKED_IMPACT_MG            CONFIG_APP_PARKED_IMPACT_MG
#define IMPACT_IMMEDIATE_MG         CONFIG_APP_IMPACT_IMMEDIATE_MG
#define IMPACT_IMMEDIATE_MAX_MS     CONFIG_APP_IMPACT_IMMEDIATE_MAX_MS
#define TOW_TILT_DEG                CONFIG_APP_TOW_TILT_DEG
#define TOW_POLL_S                  CONFIG_APP_TOW_POLL_S
#define TOW_REARM_S                 CONFIG_APP_TOW_REARM_S
#define TOW_STABLE_TENTHS           10
#define MOVEMENT_TEMPORARY_ENGINE_OFF_INTERVAL 14400
#define NO_MOVEMENT_GPS_SKIP        86400
#define DEFAULT_MOVEMENT_ALARM      IS_ENABLED(CONFIG_APP_MOVEMENT_ALARM)
#define LED_ACCEL_WAKE              IS_ENABLED(CONFIG_APP_LED_ACCEL_WAKE)
#define ACCEL_ALERT_PRIORITY        CONFIG_APP_ACCEL_ALERT_PRIORITY
#define ACCEL_ALERT_BACKOFF_S       CONFIG_APP_ACCEL_ALERT_BACKOFF_S
#define ACCEL_ALERT_BACKOFF_PRIORITY CONFIG_APP_ACCEL_ALERT_BACKOFF_PRIORITY
#define MODEM_STUCK_CFUN_S          CONFIG_APP_MODEM_STUCK_CFUN_S
#define MODEM_STUCK_RESET_S         CONFIG_APP_MODEM_STUCK_RESET_S
#define WATCHDOG_TIMEOUT_S          32
#define REG_WAIT_SLICE_S            5
#define WATCHDOG_SLEEP_SLICE_S      20
#define DATA_LIMIT                  2500
#define BATCH_SIZE                  CONFIG_APP_BATCH_SIZE
#define BATCH_HEADROOM              400
#define BATCH_FLUSH_BYTES           (UDP_PACKET_SIZE - 64 - BATCH_HEADROOM)
#define SPEED_MIN_SATS              4
#define IGN_OFF_STOPPED_KMH         3.22f
#define SPEED_FIX_MAX_AGE_MS        10000
#define LOW_POWER_STANDBY           1
#define COAST_STOP_SPEED_KMH        (CONFIG_APP_COAST_STOP_SPEED_KMH_X10 / 10.0f)
#define COAST_MAX_ITERATIONS        CONFIG_APP_COAST_MAX_ITERATIONS
#define GYRO_REST_KMH               1.0f
#define GYRO_AUTOZERO_SAMPLES       16
#define GYRO_AUTOZERO_GAP_MS        5
#define GYRO_AUTOZERO_REJECT_LSB    250
#define GYRO_AUTOZERO_EMA_SHIFT     2
#define DR_MIN_GAP_MS               2500
#define DR_MAX_GAP_MS               60000
#define DR_MOVING_KMH               3
#define FIX_GAP_WARN_MS             ((int64_t)CONFIG_APP_FIX_GAP_WARN_S * 1000)
#define FIX_GAP_MOVING_KMH          10.0f
#define FIX_GAP_WARN_SPACING_MS     60000
#define MOVEMENT_CONFIRM_MS         CONFIG_APP_MOVEMENT_CONFIRM_MS
#define MOVEMENT_CONFIRM_HITS       CONFIG_APP_MOVEMENT_CONFIRM_HITS
#define ACCEL_POLL_INTERVAL         30

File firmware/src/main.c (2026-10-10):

/*
 * Main entry + state machine.  Full port from firmware.ino including sleep
 * states, movement detection, coast-to-stop, and network error recovery.
 *
 * States:
 *   IDLE            — poll ignition/voltage, decide when to send
 *   GPS_COLLECT     — get fix, buffer a record
 *   SEND            — transmit telemetry, process response, transition
 *   IGNITION_SLEEP  — ignition ON but engine OFF; periodic sends, watch for
 *                     engine start or ignition off
 *   SLEEP           — ignition OFF; low-power loop with timer/accel/ign wake
 */

#include <string.h>
#include <stdio.h>
#include <zephyr/kernel.h>
#include <zephyr/drivers/gpio.h>
#include <zephyr/dt-bindings/gpio/nordic-nrf-gpio.h>
#include <zephyr/logging/log.h>
#include <zephyr/logging/log_ctrl.h>
#include <zephyr/pm/device.h>

#include "app.h"
#include "hw_common.h"
#include "hw_domain.h"
#include "pins.h"

LOG_MODULE_REGISTER(main, CONFIG_APP_LOG_LEVEL);

/* The PSM timers only exist in Kconfig while APP_PSM_SLEEP is on.  The code
 * that reads them is behind IS_ENABLED(), which drops the branch but still
 * compiles it, so they need a value either way. */
#ifndef CONFIG_APP_PSM_ACTIVE_S
#define CONFIG_APP_PSM_ACTIVE_S 0
#endif
#ifndef CONFIG_APP_PSM_SLEEP_GRACE_S
#define CONFIG_APP_PSM_SLEEP_GRACE_S 0
#endif

/* -- shared state used across modules (declared in app.h) ------------------ */
char     pending_server_cmd[128];
bool     read_udp_response;
bool     power_reboot;
int      gsm_send_failures;
bool     network_ready;
bool     use_cached_gps;
bool     powered_on = true;
char     ignition;
int8_t   previous_ignition = -1;
/* The last exit from sleep was the ignition line.  IDLE clears it once the
 * key is confirmed on, or reports once and sleeps if the key is already off
 * again (a short key cycle) — see the ignition-off branch there. */
static bool s_key_wake;
/* The sleep loop found the backup module taking over — by its ignition pulse
 * or by the rail poll, see do_sleep.  data.c reads and clears it. */
bool     backup_woke;
/* The sleep loop has reported the module carrying the rail, so the rail poll
 * does not report it again every pass.  Cleared by a poll that finds the rail
 * back above the band. */
static bool s_backup_seen;
bool     engine_running;
float    battery_v;
struct wake_report wake_pending;

/* -- state machine --------------------------------------------------------- */
enum main_state {
    STATE_IDLE,
    STATE_GPS_COLLECT,
    STATE_SEND,
    STATE_IGNITION_SLEEP,
    STATE_SLEEP,
};

static enum main_state s_state = STATE_IDLE;
static int64_t s_last_send_ms;
static int     s_buffered_records;
/* When a server reply was last read.  While moving, sends normally do not
 * wait for one; this is what bounds how long a setting changed on the
 * server (track mode, interval) takes to reach a driving device. */
static int64_t s_last_resp_ms;

/* -- ignition wake interrupt ----------------------------------------------- */
static K_SEM_DEFINE(s_wake_sem, 0, 1);
static struct gpio_callback s_ign_cb;
static bool s_ign_cb_installed;
/* Latched by ign_isr.  The pin level is not enough on its own: the backup
 * module's wake pulse (CONFIG_APP_BACKUP_SUPPLY) holds the line for only
 * ~0.4 s, so by the time the loop's debounce re-reads it the level is gone. */
static atomic_t s_ign_int_flag;
/* k_uptime_get_32() when ign_isr fired: where the pulse began, for timing
 * how long the line stays on. */
static atomic_t s_ign_int_ms;

/* The sleep loop owes a report the moment the modem registers (resend_owed
 * in do_sleep).  Registration used to be noticed only by the loop's own
 * poll, every RESEND_POLL_S: on 2026-09-27 the network was back at 11:50:54
 * and the ignition-off report went at 11:51:32.  Now the LTE handler ends
 * the wait as registration lands. */
static atomic_t s_report_owed;

static void report_owed_set(bool *owed, bool on)
{
    *owed = on;
    atomic_set(&s_report_owed, on ? 1 : 0);
}

/* From the LTE event handler's thread: only signal. */
static void on_registered(void)
{
    if (atomic_get(&s_report_owed)) {
        k_sem_give(&s_wake_sem);
    }
}

static void ign_isr(const struct device *dev, struct gpio_callback *cb,
                    uint32_t pins)
{
    /* Level trigger: nrfx re-arms the sense after every callback for as
     * long as the pin holds the level, so left armed this would fire
     * back-to-back and starve the sleep loop.  Disarm here; the loop
     * re-arms before each wait. */
    gpio_pin_interrupt_configure(dev, PIN_IGN_SENSE, GPIO_INT_DISABLE);
    atomic_set(&s_ign_int_ms, (atomic_val_t)k_uptime_get_32());
    atomic_set(&s_ign_int_flag, 1);
    k_sem_give(&s_wake_sem);
}

static void ign_irq_enable(void)
{
    if (!s_ign_cb_installed) {
        gpio_init_callback(&s_ign_cb, ign_isr, BIT(PIN_IGN_SENSE));
        gpio_add_callback(hw_gpio0, &s_ign_cb);
        s_ign_cb_installed = true;
    }
    /* Level, not edge.  An edge trigger takes a GPIOTE IN channel, which
     * keeps the pin-detect logic clocked for the whole sleep (~20-45 uA on
     * the SiP per Nordic); a level trigger goes through the PORT/sense
     * path, which costs nothing.  One direction is enough: sleep is only
     * ever entered with the ignition off, so the only transition that can
     * matter is the sense pin going low (ignition present).  The awake
     * side polls ignition and is untouched by this. */
    gpio_pin_interrupt_configure(hw_gpio0, PIN_IGN_SENSE, GPIO_INT_LEVEL_LOW);
}

static void ign_irq_disable(void)
{
    gpio_pin_interrupt_configure(hw_gpio0, PIN_IGN_SENSE, GPIO_INT_DISABLE);
}

/* -- console suspend across the sleep wait ---------------------------------- */
/* An enabled UARTE holds the HF clock even with no traffic (~600-900 uA at
 * 3.3 V — the bulk of the parked board's input draw).  The console is
 * suspended only for the blocking wait in do_sleep(), so everything logged
 * while awake still reaches the port.  A message logged mid-wait is dropped
 * harmlessly: with the device suspended the driver's tx path is a no-op.
 *
 * A quiet sleep pass (a tilt poll that finds nothing) runs with the console
 * still suspended — see the quiet test in do_sleep().  Both calls are no-ops
 * in the state they would set, so console_resume() can be dropped in front
 * of any branch that logs without tracking whether it already ran. */
#if DT_HAS_CHOSEN(zephyr_console)
static const struct device *const s_console_dev =
    DEVICE_DT_GET_OR_NULL(DT_CHOSEN(zephyr_console));
#else
static const struct device *const s_console_dev = NULL;
#endif
static bool s_console_on = true;

static void console_suspend(void)
{
    if (!s_console_on || s_console_dev == NULL ||
        !device_is_ready(s_console_dev)) {
        return;
    }

    /* Bounded drain of the deferred log queue so the tail isn't lost. */
    for (int i = 0; i < 40 && log_data_pending(); i++) {
        k_msleep(5);
    }
    k_msleep(2);

    int err = pm_device_action_run(s_console_dev, PM_DEVICE_ACTION_SUSPEND);
    if (err && err != -EALREADY) {
        static bool s_warned;
        if (!s_warned) {
            s_warned = true;
            LOG_WRN("console suspend failed (%d)", err);
        }
        return;
    }
    s_console_on = false;
}

static void console_resume(void)
{
    if (s_console_on || s_console_dev == NULL ||
        !device_is_ready(s_console_dev)) {
        return;
    }
    (void)pm_device_action_run(s_console_dev, PM_DEVICE_ACTION_RESUME);
    s_console_on = true;
}

/* -- accelerometer wake interrupt ------------------------------------------ */
static struct gpio_callback s_accel_cb;
static bool s_accel_cb_installed;
static atomic_t s_accel_int_flag;
/* True while the sleep-side level trigger is armed on INT1.  The ISR must
 * disarm a level trigger (see ign_isr) but must leave the awake-side edge
 * trigger alone, or the second impact of a drive would never be seen. */
static atomic_t s_accel_level_armed;

static void accel_isr(const struct device *dev, struct gpio_callback *cb,
                      uint32_t pins)
{
    /* Same as ign_isr: the sleep-side trigger is a level, so disarm before
     * nrfx can re-arm it.  The awake-side crash trigger is an edge and
     * stays armed. */
    if (atomic_get(&s_accel_level_armed)) {
        gpio_pin_interrupt_configure(dev, PIN_ACC_INT1, GPIO_INT_DISABLE);
    }
    atomic_set(&s_accel_int_flag, 1);
    k_sem_give(&s_wake_sem);
}

static void accel_cb_install(void)
{
    if (!s_accel_cb_installed) {
        gpio_pin_configure(hw_gpio0, PIN_ACC_INT1, GPIO_INPUT);
        gpio_init_callback(&s_accel_cb, accel_isr, BIT(PIN_ACC_INT1));
        gpio_add_callback(hw_gpio0, &s_accel_cb);
        s_accel_cb_installed = true;
    }
}

static void accel_irq_enable(void)
{
    if (!accel_available()) return;
    accel_cb_install();
    accel_enable_wake_int();
    /* Drop anything latched before this arming — a stale flag from the awake
     * path, or the FS/ODR step that fires a spurious wake ~26 ms into
     * accel_enable_wake_int() — so the first sleep iteration doesn't confirm
     * a phantom.  Cleared before the GPIO interrupt is armed, never after,
     * or a real edge arriving here would be swallowed. */
    atomic_clear(&s_accel_int_flag);
    /* Level trigger for the same reason as the ignition wake: no GPIOTE IN
     * channel held for the whole sleep.  INT1 is an active-high pulse that
     * idles low, so level-high is the same event as the rising edge. */
    atomic_set(&s_accel_level_armed, 1);
    gpio_pin_interrupt_configure(hw_gpio0, PIN_ACC_INT1, GPIO_INT_LEVEL_HIGH);
}

static void accel_irq_disable(void)
{
    if (!accel_available()) return;
    atomic_clear(&s_accel_level_armed);
    gpio_pin_interrupt_configure(hw_gpio0, PIN_ACC_INT1, GPIO_INT_DISABLE);
    accel_disable_wake_int();
}

/* -- crash (impact) interrupt while awake ----------------------------------- */
static void crash_irq_enable(void)
{
    if (!accel_available()) return;
    accel_cb_install();
    atomic_clear(&s_accel_level_armed);
    atomic_clear(&s_accel_int_flag);
    accel_fifo_enable();
    accel_crash_int_enable(CRASH_THRESHOLD_MG);
    gpio_pin_interrupt_configure(hw_gpio0, PIN_ACC_INT1,
                                 GPIO_INT_EDGE_TO_ACTIVE);
}

static void crash_irq_disable(void)
{
    if (!accel_available()) return;
    gpio_pin_interrupt_configure(hw_gpio0, PIN_ACC_INT1, GPIO_INT_DISABLE);
    accel_crash_int_disable();
    accel_fifo_disable();
}

/* -- accelerometer alert priority backoff ----------------------------------
 *
 * Impact, tilt/tow and movement all raise the same high-priority alert, and
 * one physical event routinely trips several of them: opening the glovebox a
 * tracker lives in produces a movement alert, then a tilt alert, then another
 * movement alert.  Waking someone once for that is useful.  Waking them four
 * times teaches them to ignore the alerts entirely, which is worse than not
 * sending any.
 *
 * So the first alert goes out at full priority and opens a window.  Anything
 * inside the window is reported at APP_ACCEL_ALERT_BACKOFF_PRIORITY instead:
 * still sent, still logged, still in the history — just not urgent.
 *
 * The window is fixed rather than sliding.  Once it expires the next event is
 * urgent again, so sustained interference keeps producing high-priority
 * alerts at one per window, rather than being silenced indefinitely by its
 * own persistence.
 */
static int64_t s_accel_alert_window_end;

static int accel_alert_priority(void)
{
    if (ACCEL_ALERT_BACKOFF_S <= 0) {
        return ACCEL_ALERT_PRIORITY;          /* backoff disabled */
    }

    int64_t now = k_uptime_get();

    if (s_accel_alert_window_end && now < s_accel_alert_window_end) {
        LOG_INF("accel alert downgraded to priority %d (%lld s of backoff left)",
                ACCEL_ALERT_BACKOFF_PRIORITY,
                (s_accel_alert_window_end - now) / 1000);
        return ACCEL_ALERT_BACKOFF_PRIORITY;
    }

    s_accel_alert_window_end = now + (int64_t)ACCEL_ALERT_BACKOFF_S * 1000;
    return ACCEL_ALERT_PRIORITY;
}

/* Called from the awake loops.  The FIFO ring holds ~7 s of accel+gyro,
 * and nothing else drains it while the interrupt flag is up (see
 * dr_fifo_service()), so the impact profile is intact even with loop-cadence
 * latency. */
static void crash_check(void)
{
    if (!atomic_clear(&s_accel_int_flag)) return;

    uint8_t src = 0;
    accel_read_wake_src(&src);

    struct accel_impact imp;
    char msg[120];
    if (accel_fifo_drain_impact(&imp) == 0 && imp.samples > 0) {
        snprintf(msg, sizeof(msg),
                 "impact %d.%02dg x=%d y=%d z=%d gyr=%d.%ddps dur=%dms spd=%.1f",
                 imp.peak_mg / 1000, (imp.peak_mg % 1000) / 10,
                 imp.pax, imp.pay, imp.paz,
                 imp.peak_gyro_dps10 / 10, imp.peak_gyro_dps10 % 10,
                 imp.over_ms, (double)g_gnss.speed_kmh);
    } else {
        int ax, ay, az;
        accel_read(&ax, &ay, &az);
        snprintf(msg, sizeof(msg),
                 "impact: >%d.%dg (src=0x%02x) now=%d/%d/%dmg spd=%.1f",
                 CRASH_THRESHOLD_MG / 1000, (CRASH_THRESHOLD_MG % 1000) / 100,
                 src, ax, ay, az, (double)g_gnss.speed_kmh);
    }
    LOG_WRN("%s", msg);
    alert_enqueue(msg, accel_alert_priority());
    alert_send();
}

#if IS_ENABLED(CONFIG_APP_DEAD_RECKONING)
/* The FIFO into the dead reckoning.  Not with an impact waiting for
 * crash_check(): its profile is in the FIFO, and the FIFO gives each sample
 * once.  The impact drain feeds the dead reckoning as well, so waiting for
 * it loses nothing.  Not with the key off either: no drive to fill in. */
void dr_fifo_service(void)
{
    if (ignition == 0 && !atomic_get(&s_accel_int_flag)) {
        (void)accel_fifo_service();
    }
}
#endif
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
int main(void)
{
    LOG_INF("=== l0destar firmware boot (v%s, board %s) ===",
            fota_version(), fota_board_id());

    /* Why this boot happened, on the console, now.  It also rides out with
     * the first record as rst=, but a unit that resets during bring-up
     * never gets that far — which is exactly when the answer matters, and
     * is how a reset loop hides what is resetting it.  Reading it here does
     * not consume it: both accessors cache, so the record still carries it.
     *
     * "on probation" means MCUboot swapped this image in as a test and will
     * take it back out unless the bring-up below completes. */
    {
        const char *rst = dbglog_reset_cause();

        LOG_INF("reset cause: %s%s", rst ? rst : "(none reported)",
                fota_image_on_probation() ? " — image on probation" : "");
    }

    /* Before anything that can take time, and long before the radio.
     *
     * It used to be armed at the end of bring-up, after the modem connect
     * and the A-GNSS fetch, some eleven seconds in.  That is too late in
     * both directions.  The nRF watchdog cannot be stopped once started and
     * survives a soft reset, so a unit that reboots for any reason — a FOTA
     * swap, a fatal error — comes up with the previous image's watchdog
     * still counting down its 12 s window and nothing feeding it until the
     * app takes ownership.  Bring-up is longer than the window, so the boot
     * dies at the same point every time, which is a reset loop that no
     * amount of reflashing over the air can break: the new image never
     * lives long enough to confirm itself and MCUboot reverts it.
     *
     * Taking ownership here instead feeds the stale watchdog within a
     * couple of hundred milliseconds (task_wdt allocates the same hardware
     * channel the previous image did, so the reload lands on the running
     * one), and everything slow below already kicks as it waits. */
    if (!APP_HARNESS_BUILD) {
        watchdog_init();
    }

    /* Before anything tries to update again: work out whether the update
     * staged before the last reboot is the one now running.  It queues an
     * alert and a line for the server if MCUboot reverted it, which is what
     * stops a bad image being downloaded over and over with the engine
     * off — the one failure mode of this that flattens a car battery. */
    fota_verdict_on_boot();

#if defined(CONFIG_APP_PROVISION_MODE)
    /* Provisioning build (prov.conf): bring up the modem library so the AT
     * Host library can bridge nrfcloud-utils <-> modem (AT%KEYGEN, cert
     * install) for nRF Cloud onboarding, then idle.  No LTE needed.  After
     * onboarding, reflash the normal build — the device key/cert persist in
     * modem NVM at CONFIG_NRF_CLOUD_SEC_TAG. */
    printk("\n*** PROVISIONING MODE — AT host ready; run nrfcloud-utils ***\n");
    (void)modem_init();
    for (;;) {
        k_sleep(K_FOREVER);
    }
#endif

    if (crypto_init()) {
        LOG_ERR("crypto init failed — halting");
        return 0;
    }
    settings_load();

    if (hw_gpio_init()) {
        LOG_ERR("gpio init failed — halting");
        return 0;
    }

    hw_domain_init();
    hw_aux_power_on();
    k_msleep(10);

#if IS_ENABLED(CONFIG_APP_LTE_POWER_TEST)
    /* LTE TX power / brown-out rig: idles with LED1 on, blasts uplink
     * traffic on ENTER.  Skips the self-test and every peripheral the
     * radio doesn't need.  Never returns. */
    lte_power_test_run();
#endif

    /* Tests 1 and 2 of the board test walk the same rails interactively, so
     * at boot the self-test would only cycle them a second time and bury the
     * operator's prompt under its own log. */
    if (!IS_ENABLED(CONFIG_APP_BOARD_TEST)) {
        hw_selftest();
    }

    /* A part on the I2C bus that did not answer.
     *
     * The warnings already reach the captured log, but a log line is
     * something you find after going to look, and these are silent losses of
     * what the device is for: with no accelerometer there is no movement,
     * impact or tow detection, and with no INA228 there is no battery
     * voltage — which the low-battery alert, the sleep safety gate and the
     * engine-running fallback all read.  The unit carries on reporting
     * position exactly as though it were whole, so without an alert nothing
     * would ever say otherwise.  Seen on a new bench build on 2026-09-24,
     * where the INA228 did not ACK while the accelerometer on the same bus
     * was fine.
     *
     * Queued, not sent: the radio is not up yet, so these ride out with the
     * first record.  Once per boot — there is no persistent store to
     * remember having said it, so a board with a dead part reports again
     * after every restart, FOTA reboots included. */
    if (hw_power_init()) {
        LOG_WRN("INA228 init failed — voltage unavailable");
        alert_enqueue("INA228 not responding (I2C): no battery voltage",
                      CONFIG_APP_HW_FAULT_PRIORITY);
    }
    if (hw_accel_init()) {
        LOG_WRN("accel init failed — readings unavailable");
        alert_enqueue("accelerometer not responding (I2C): no movement, "
                      "impact or tow detection",
                      CONFIG_APP_HW_FAULT_PRIORITY);
    }
    if (hw_can_init())    LOG_WRN("CAN controller init failed");
    if (IS_ENABLED(CONFIG_APP_BOARD_HAS_L_SENSE) && kline_l_sense_init()) {
        LOG_WRN("L sense init failed — no L-line short detection");
    }

#if IS_ENABLED(CONFIG_APP_BOARD_TEST)
    /* Interactive bring-up rig (board_test.sh): walks the operator through
     * every fitted subsystem over the console, then parks.  Never returns. */
    board_test_run();
#endif

#if IS_ENABLED(CONFIG_APP_ACCEL_TEST)
    if (accel_available()) {
        printk("\n*** ACCEL TEST — streaming at 10 Hz ***\n");
        printk("ax,ay,az,gx,gy,gz,temp\n");
        for (;;) {
            int ax, ay, az, gx = 0, gy = 0, gz = 0;
            float temp = 0;
            accel_read(&ax, &ay, &az);
            accel_read_gyro(&gx, &gy, &gz);
            accel_read_temp(&temp);
            printk("%d,%d,%d,%d,%d,%d,%.1f\n",
                   ax, ay, az, gx, gy, gz, (double)temp);
            k_msleep(100);
        }
    }
#endif

#if IS_ENABLED(CONFIG_APP_L_SENSE_TEST)
    kline_l_sense_test();   /* streams the L-line sense; never returns */
#endif

#if IS_ENABLED(CONFIG_APP_CAN_BENCH)
    can_bench_run();   /* host-driven CAN test target; never returns */
#endif

#if IS_ENABLED(CONFIG_APP_CAN_TEST)
    hw_can_test();
    printk("CAN test complete — halting.\n");
    for (;;) { k_msleep(10000); }
#endif

#if IS_ENABLED(CONFIG_APP_VOLTAGE_TEST)
    printk("\n*** VOLTAGE TEST — streaming INA228 VBUS at 2 Hz ***\n");
    if (!hw_power_available()) {
        printk("INA228 not available — nothing to read.\n");
    }
    for (;;) {
        float v = battery_read_voltage();
        if (v < 0.0f) {
            printk("read failed\n");
        } else {
            printk("VBUS=%.3f V\n", (double)v);
        }
        k_msleep(500);
    }
#endif

#if IS_ENABLED(CONFIG_APP_KLINE_TEST)
    kline_test();
    printk("K-line test complete — halting.\n");
    for (;;) { k_msleep(10000); }
#endif

#if IS_ENABLED(CONFIG_APP_KLINE_DISCOVER)
    /* One-shot investigation of an unknown vehicle: hunt the protocol,
     * rate and ECU addresses, ask each responder what it supports, and
     * finish with a summary and a suggested local.conf.  Slow and noisy by
     * design — run it once per vehicle, then configure the runtime path
     * from what it prints.  Parks afterwards so the console log survives:
     * going on to the modem would let the power-on FOTA check swap this
     * image out mid-investigation. */
    kline_boot_res = kline_discover(&kline_boot_disc);

    while (1) {
        status_delay(1000);
    }
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

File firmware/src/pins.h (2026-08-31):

#ifndef PINS_H_
#define PINS_H_

/* PCB pin assignments — P0.x GPIO numbers, -1 = not fitted on this board.
 *
 * All values come from Kconfig (APP_PIN_*).  The per-board defaults live in
 * Kconfig.boards, selected by the APP_BOARD choice; a bench or board variant
 * can still remap any signal from local.conf without touching code. */
#define PIN_K1_TX      CONFIG_APP_PIN_K1_TX
#define PIN_K1_RX      CONFIG_APP_PIN_K1_RX
#define PIN_K2_TX      CONFIG_APP_PIN_K2_TX
#define PIN_K2_RX      CONFIG_APP_PIN_K2_RX
#define PIN_L_SEND     CONFIG_APP_PIN_L_SEND
#define PIN_L_RECV     CONFIG_APP_PIN_L_RECV
#define PIN_L_SENSE    CONFIG_APP_PIN_L_SENSE
#define PIN_K_EN       CONFIG_APP_PIN_K_EN
#define PIN_K_SLEEP    CONFIG_APP_PIN_K_SLEEP
#define PIN_AUX_SW     CONFIG_APP_PIN_AUX_SW
#define PIN_OBD_EN     CONFIG_APP_PIN_OBD_EN
#define PIN_CAN_EN     CONFIG_APP_PIN_CAN_EN
#define PIN_TWI_SDA    CONFIG_APP_PIN_TWI_SDA
#define PIN_TWI_SCL    CONFIG_APP_PIN_TWI_SCL
#define PIN_INA_ALRT   CONFIG_APP_PIN_INA_ALRT
#define PIN_ACC_INT1   CONFIG_APP_PIN_ACC_INT1
#define PIN_ACC_INT2   CONFIG_APP_PIN_ACC_INT2
#define PIN_IGN_SENSE  CONFIG_APP_PIN_IGN_SENSE

/* MCP2518FD CAN controller (SPI bit-banged; -1 on boards without CAN) */
#define PIN_CAN_SCK    CONFIG_APP_PIN_CAN_SCK
#define PIN_CAN_SDI    CONFIG_APP_PIN_CAN_SDI
#define PIN_CAN_SDO    CONFIG_APP_PIN_CAN_SDO
#define PIN_CAN_CS     CONFIG_APP_PIN_CAN_CS
#define PIN_CAN_INT    CONFIG_APP_PIN_CAN_INT

/* Status LEDs (-1 = not fitted; LED4/5 exist only on v2.1 mini) */
#define PIN_LED1       CONFIG_APP_PIN_LED1
#define PIN_LED2       CONFIG_APP_PIN_LED2
#define PIN_LED3       CONFIG_APP_PIN_LED3
#define PIN_LED4       CONFIG_APP_PIN_LED4
#define PIN_LED5       CONFIG_APP_PIN_LED5

/* Switched-rail status sense inputs (v3.1+).  The 3.3V senses read high
 * while their rail is up; the 12V sense is inverted by a 2N7002 and reads
 * low while PP12V_K is up (CONFIG_APP_BOARD_RAIL_ST_12V_ACTIVE_LOW). */
#define PIN_GPS_RAIL_ST    CONFIG_APP_PIN_GPS_RAIL_ST
#define PIN_CAN_RAIL_ST    CONFIG_APP_PIN_CAN_RAIL_ST
#define PIN_K3V3_RAIL_ST   CONFIG_APP_PIN_K3V3_RAIL_ST
#define PIN_K12V_RAIL_ST   CONFIG_APP_PIN_K12V_RAIL_ST

/* 0-30V AIO inputs (v2.1 only) */
#define PIN_AIO1       CONFIG_APP_PIN_AIO1
#define PIN_AIO2       CONFIG_APP_PIN_AIO2
#define PIN_AIO3       CONFIG_APP_PIN_AIO3
#define PIN_AIO4       CONFIG_APP_PIN_AIO4
#define PIN_AIO5       CONFIG_APP_PIN_AIO5
#define PIN_AIO6       CONFIG_APP_PIN_AIO6

/* INA and accelerometer share the TWIM bus */
#define PIN_INA_SDA    PIN_TWI_SDA
#define PIN_INA_SCL    PIN_TWI_SCL
#define PIN_ACC_SDA    PIN_TWI_SDA
#define PIN_ACC_SCL    PIN_TWI_SCL

#endif

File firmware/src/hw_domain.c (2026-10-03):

/*
 * Switched power-domain sequencing.
 *
 * Every l0destar PCB gates parts of the circuit behind GPIO-controlled rails
 * (load switches / FETs / buck enables).  Any nRF pin that terminates inside
 * a switched domain must never be driven high while that domain is off: the
 * peripheral's ESD clamps sit at VDD + 0.3 V (MCP2518FD) or VCCA + 0.5 V
 * (TXS0104E), so a high pin backfeeds the dead rail through the clamp
 * diodes.  Pull-ups that live on a switched rail (CAN_INT/CAN_CS 10K,
 * v3.0/v3.1 K_TX/K_RX 10K) float when it is down, so inputs get the nRF
 * internal pulldown while parked.
 *
 * Rules implemented here:
 *   - park  (domain off): every domain pin -> INPUT | PULL_DOWN.  The nRF
 *     sources nothing, floating pull-ups are defeated.
 *   - release (domain on): outputs that idle low (SPI SCK/SDI, L_SEND,
 *     K_SLEEP) -> OUTPUT_LOW; everything else -> INPUT no-pull, letting the
 *     now-powered board pull-ups define the idle level (CS/INT high, K
 *     recessive).
 *   - order: release pins BEFORE raising the enable (inputs float up with
 *     the rail via their pull-ups; low outputs source nothing), park pins
 *     BEFORE dropping the enable.
 *
 * Domains are reference-counted so shared rails (v3.0 OBD feeds both CAN
 * and K-line; AUX feeds GPS bias plus, on v2.x, the OBD circuits) only drop
 * when the last user lets go.  v3.1 splits OBD into independent CAN_EN and
 * K_EN domains, so the unused interface never has to be powered.
 *
 * v3.1 also feeds each rail's actual state back on a sense input, so the
 * enable is no longer taken on trust: hw_domain_request() waits for the
 * sense line(s) before it reports success, and re-parks everything and
 * fails if the rail never appears.  Without that check a failed load switch
 * would leave the drivers bit-banging 3.3 V into an unpowered MCP2518FD or
 * TJA1027T through their clamp diodes — exactly what the parking rules above
 * exist to prevent.
 *
 * A domain with no signal pins (v3.x AUX: GPS_ENABLE gates only the antenna
 * bias tee) has nothing to protect, so a rail that fails to report up is
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

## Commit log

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2026-06-09 replaced the voltage divider that derives the ignition signal with a MOSFET gating the 3.3v rail
    [ignition_presence_sensing.kicad_sch, l0destar.kicad_pcb, l0destar.kicad_sch]
2026-06-12 gyro + temperature telemetry, impact detection, changelog
    - enable the ASM330LHHX gyro (104 Hz ±250 dps) and IMU temp; emit
    gx/gy/gz and mt in telemetry records; ax/ay/az now in milli-g
    - impact detection while awake: ±8 g accel, high-g interrupt
    (APP_CRASH_THRESHOLD_MG), 26 Hz accel+gyro FIFO ring drained on
    impact for a forensic alert (peak g/axis, rotation, duration, speed)
    plus serial waveform dump
    - parked-impact classification from the FIFO true peak on unconfirmed
    movement wakes (APP_PARKED_IMPACT_MG); 100 ms settle after FS changes
    fixes a spurious wake/false impact on every sleep entry
    - bench stub tweaks (battery 12.4 V, ignition off); README impact
    section; CHANGEL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
    [config.h, hw_accel.c, hw_power.c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]
2026-06-12 pre-merge cleanup: dead symbols, stale docs, orphaned stubs
    - drop unused NRF_CLOUD_KEY Kconfig symbol (eval-token auth was abandoned
    for device JWT) and its README legacy note
    - fix stale agnss.c header comment (described eval-key auth, code uses JWT)
    - delete orphaned src/stubs.c (superseded by APP_DEBUG_* overrides)
    - README Kconfig table: replace dead DK_PIN_WORKAROUNDS row with the pin
    map, relay/debug overrides and impact thresholds
    - CHANGELOG: cover the pin abstraction + debug-override refactor
2026-06-12 tow/jack + tamper theft detection while parked
    - tow/jack: poll the gravity vector against a sleep-entry reference every
    APP_TOW_POLL_S; sustained tilt past APP_TOW_TILT_DEG raises an alert.
    Catches slow flatbed lifts / jacking that never trip the motion wake.
    - tamper: arm the IMU 6D orientation engine during sleep; an orientation
    zone change vs the armed face raises a tamper alert. Checked on every
    wake via zone compare (the no-latch event flag de-asserts too fast to
    catch from the loop).
    - swallow the 6D engine's initial-orientation classification at arm time so
    it doesn't false-fire on sleep entry.
    - alert strings: em-dash -> ASCII hyphen so they round-trip cleanly to the
    s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
    [config.h, hw_accel.c, main.c]
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2026-06-12 fix date
    [l0destar.kicad_pcb, l0destar.kicad_sch]
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2026-06-13 Gyro zero-rate bias auto-zero (v0.2.1)
    Learn the ASM330's temperature-dependent gyro offset while stopped (good
    GNSS fix, speed < GYRO_REST_KMH) by averaging a short burst of raw samples
    and EMA-tracking it, then subtract from every gx/gy/gz read. Bench data
    showed gy ~ -132 LSB (~-1.2 dps) at rest.
    accel_read_gyro() now returns raw-minus-bias so existing callers (telemetry,
    impact FIFO peak) get corrected values. A per-burst rotation reject guards
    against a stale/zero GNSS speed corrupting the offset during motion.
    [config.h, hw_accel.c]
2026-06-20 Remap GPIO pin assignments and enable the latching relay
    New P0.x map (production PCB): K1 RX/TX=21/22, K2 RX/TX=23/24, AUX_SW=10,
    I2C SCL/SDA=4/5, VBAT_ALRT=11, ACC_INT1/2=2/3, IGN_SENSE=31, RLY_SET=12,
    RLY_RST=30, RLY_SET_FB/RST_FB=7/6.
    - Enable APP_RELAY_CONNECTED by default; relay_init() still self-detects an
    absent relay (both feedback lines low) and no-ops, so it's bench-safe.
    - IGN_SENSE is now active-low (low = ignition on): flip ignition_read() and
    add a pull-up so a disconnected line reads OFF.
    - Overlay: drop the now-obsolete UART1 disable (its pins are unused by the
    new map); I2C2 (P0.30/31) and SPI3 (P0.11/12) stay disabled as they still
    collide with the relay/ignition/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
    [hw_power.c]
2026-06-20 Switch telemetry transport to TLS/TCP (default), keep DTLS as opt-out
    Enable APP_TRANSPORT_TLS by default so telemetry uses modem-offloaded
    TLS 1.2 over TCP (port 65481) instead of DTLS 1.2 over UDP (65482).
    DTLS/UDP to the self-hosted endpoint was timing out over cellular
    (transport: connect: 116 / ETIMEDOUT) while TCP/TLS to nRF Cloud kept
    working on the same link — UDP NAT bindings expire and inbound UDP to a
    self-hosted IP is easily dropped, so TCP/TLS is the more reliable path.
    transport.c selects SOCK_STREAM/IPPROTO_TLS_1_2 and tears the socket
    down after each send (fresh connection per send, session-cache resumed);
    alert.c closes the connection after draining the alert queue. Same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
    [transport.c]
2026-06-30 Auto-select board profile (DK vs Makerdiary) from attached probe
    build.sh now picks a board profile from the debug probe present: the Makerdiary
    nRF9151 Connect Kit when its CMSIS-DAP probe shows up in `pyocd list`, otherwise
    the Nordic DK. Override with PROFILE=dk|makerdiary.
    The Makerdiary profile layers makerdiary.{conf,overlay} (gitignored, bench-local)
    on the nrf9151dk board target to move the console onto the board's USB-serial
    bridge pins (P0.11/P0.12) and re-park the colliding INA_ALRT/RLY_SET GPIOs.
    Switching profiles forces a pristine rebuild so the other board's cached
    devicetree/Kconfig can't linger.
2026-06-30 Build the real nrf9151_connectkit target for the Makerdiary profile
    The Makerdiary profile now builds the vendored nrf9151_connectkit board target
    (boards/makerdiary/, found via BOARD_ROOT) instead of layering a console remap
    on the DK target. This fixes GPS on the Connect Kit: the DK target enables
    MODEM_ANTENNA and sends AT%XCOEX0=1,1,1565,1586 to drive the DK's onboard-GNSS
    RF switch, which mis-routes GNSS on the Makerdiary's RF front end. The real
    target leaves MODEM_ANTENNA off (modem default), as Makerdiary ships.
    build.sh selects the board target per profile (dk -> nrf9151dk, makerdiary ->
    nrf9151_connectkit) and folds the target into the pristine-on-switch marker.
    The vendored board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
2026-07-19 update prototype hardware:
    - added v2.1 boards
    - removed earlier prototypes that were either failed or non-viable
    [accelerometer.kicad_sch, aio_pins.kicad_sch, antenna_bias_tee.kicad_sch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]
2026-07-20 fix LED footprint and mount 5 of them vertically
    [l0destar.kicad_pcb, l0destar.kicad_sch, status_led.kicad_sch]
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2026-08-01 fix reference
    [buck_converter.kicad_sch]
2026-08-01 fix TVS part
    [main_power_input.kicad_sch]
2026-08-01 fix references
    [l0destar.kicad_sch]
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2026-08-02 added missing stiching vias
    [l0destar.kicad_pcb]
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2026-08-02 fix cap reference
    [l0destar.kicad_pcb, main_power_input.kicad_sch]
2026-08-02 fix L9637D cap positions
    [l0destar.kicad_pcb]
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2026-08-05 Fix JLCPCB name in RF trace width notes across hardware README files
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2026-08-05 fix discrepencies
    [accelerometer.kicad_sch, antenna_bias_tee.kicad_sch, auxillary_power_control.kicad_sch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]
2026-08-07 fixed voltage spec for buck output caps
    [l0destar.kicad_pcb, l0destar.kicad_sch]
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2026-08-09 - Added missing 510R pullup resistor to the L line on v2.5k and v2.6k - Added v2.5k test results
    [iso-9141_interface.kicad_sch, l0destar.kicad_pcb]
2026-08-09 - Fixed a few discrepencies in the BOM / parts lists - Added v3.1 board with relay power switching added back in as a configurable build option, keeping the same PCB footprint - Added v3.2 board with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
    [accelerometer.kicad_sch, antenna_bias_tee.kicad_sch, auxillary_power_control.kicad_sch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]
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2026-08-10 fix power draw after motion wakes
    [main.c]
2026-08-11 remove these for now, the relay doesn't make sense with ~120uA quiescent current
    [accelerometer.kicad_sch, antenna_bias_tee.kicad_sch, auxillary_power_control.kicad_sch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]
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2026-08-15 add ISO-9141 fixes/test code and update test results for v2.6k
    [hw_kline.c, main.c]
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2026-08-16 fix pulldown resistor spec
    [main_power_input.kicad_sch]
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2026-08-16 fix bias tee cap ordering on all boards
    [l0destar.kicad_pcb]
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2026-08-16 bugfixes and add ifmcu power state patch
    [hw_kline.c]
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2026-08-16 fix send frequency, avoid buffering
    [transport.c]
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2026-08-16 optimised send loop and fixed startup lag
    [main.c, transport.c]
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2026-08-21 - Always reports ignition ON/OFF transitions even when GNSS has no fix by sending the last known position with `cl=1`, preventing missed “parked indoors/garage” ignition-off events. - Sets speed and 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
    - Adds a per-bu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
    [main.c]
2026-08-23 fix v3.1 firmware bugs
    [hw_can.c, hw_domain.c, hw_kline.c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]
2026-08-23 - Always reports ignition ON/OFF transitions even with no GNSS fix by sending the last known position flagged as stale (`cl=1`), preventing missed key-off events when parked indoors/garages. - Sets s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
2026-08-23 fix sheet annotations
    [accelerometer.kicad_sch, antenna_bias_tee.kicad_sch, auxillary_power_control.kicad_sch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]
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2026-08-31 remove references to the relay as this is no longer part of any recent designs
2026-08-31 schematic<>readme discrepency fixes
    [accelerometer.kicad_sch, antenna_bias_tee.kicad_sch, auxillary_power_control.kicad_sch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]
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2026-08-31 243K, changed my mind. hysteresis doesn't actually work if EN never goes low
    [buck_converter.kicad_sch, l0destar.kicad_pcb]
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2026-09-01 fixed the 0508 footprint in v3.3 to actually match the part dimensions properly, saving precious microns of board real estate
    [antenna_bias_tee.kicad_sch, iso-9141_interface.kicad_sch, l0destar.kicad_pcb]
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2026-09-03 fix errors and discrepencies
    [build_html.py]
2026-09-03 update - fix errors and discrepencies
    [build_html.py]
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2026-09-05 fix timing issue causing agnss to fail (http request blocked by the GPS device)
    [config.h, main.c]
2026-09-05 fix references to ISO-9141 to refer to the k-wire as ISO-9141 isn't the only supported protocol
2026-09-06 multiple stability improvements, fixed battery readings skewed by noise
    [config.h, dbglog.c, hw_power.c]
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2026-09-08 add v3.4 with accelerometer symbol fix, huge quiescent current saving
    [accelerometer.kicad_sch, antenna_bias_tee.kicad_sch, auxillary_power_control.kicad_sch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]
2026-09-11 GPS rail fault firmware fixes
    [hw_domain.c, hw_selftest.c]
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2026-09-12 stop pyocd mass-erasing the nRF9151 on reset
    reset.sh had started wiping the board instead of rebooting it. Every pyocd
    connect to an nRF91 runs check_flash_security before discovery: it reads
    CTRL-AP APPROTECTSTATUS and, when the part reports APPROTECT or SECUREAPPROTECT
    engaged, issues CTRL-AP ERASEALL to regain debug access. The session option
    that governs this, auto_unlock, defaults to true, so the erase is silent and
    takes about a second, wiping application flash and UICR.
    reset.sh itself never changed. Ending flash.sh with a pin reset did: the soft
    reset it replaced left the SoC in debug interface mode, where the debug port
    stays enabled and APPROTECT is never re-armed, so every later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
2026-09-12 switch network mode to LTE-M only
    CONFIG_LTE_NETWORK_MODE_LTE_M_GPS replaces
    CONFIG_LTE_NETWORK_MODE_LTE_M_NBIOT_GPS in prj.conf, so NB-IoT is no longer
    enabled in %XSYSTEMMODE and the modem cannot fall back to it where LTE-M is
    unreachable. That reverses the earlier rationale of keeping NB-IoT as a
    fallback for patchy LTE-M coverage. GNSS is untouched.
    CONFIG_LTE_MODE_PREFERENCE_LTE_M has to go with it: every
    CONFIG_LTE_MODE_PREFERENCE_* symbol depends on LTE_NETWORK_MODE_LTE_M_NBIOT or
    LTE_NETWORK_MODE_LTE_M_NBIOT_GPS, so against a single-RAT mode it is an unmet
    dependency, and Zephyr treats the resulting Kconfig warning as an error.
    lte_link_control falls back to preference 0 (auto), whi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
2026-09-12 improve reporting of connectivity issues
    [dbglog.c, main.c]
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2026-09-12 improve rail fail notifications
    [hw_domain.c]
2026-09-12 cleanup and chip swap
    [can_interface.kicad_sch, l0destar.kicad_pcb]
2026-09-12 prevent a lost datagram silencing a unit
    [config.h]
2026-09-13 server tests: clear the dtc table between integration tests
    The database fixture emptied every table except dtc. With foreign key
    checks off the device rows went and their fault codes stayed behind, so
    a second run against the same database found the first run's codes still
    active and the fault code tests failed.
    Claude-Session: https://claude.ai/code/session_013xHArr59EbXDPrh23Ai2UE
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2026-09-13 server: refuse telemetry on the TLS port unless tls_telemetry is set
    The TLS listener takes a device's word for its identity: a frame is
    attributed to whichever enrolled IMEI it starts with. The port has to be
    open to the internet for firmware downloads, so anyone who learned an
    IMEI could post positions, alerts and fault codes as that device, block
    its updates with a forged revert report, and collect the commands queued
    for it. Current firmware reports over UDP with its own key and only
    comes to this port for updates.
    Telemetry frames are now refused, and logged, unless tls_telemetry is
    set; firmware downloads are served either way. The dispatch moves into
    serve() so it can be tested ov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
2026-09-13 server: web UI and API for more than one vehicle
    The map page followed whichever device default_device named, and nothing
    in the interface could show another. Now:
    - /devices lists every enrolled device with its latest record - state,
    battery, speed, firmware and network - each linking to its own map.
    - / opens the map for default_device, or for the only enrolled device,
    and the device list otherwise; /track without a device it can resolve
    opens the list too.
    - The map page names its device on every request it makes and on the
    live WebSocket, links to the list when there is more than one device,
    and learns the track-mode forward axis per device, since each unit is
    mounted its o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
2026-09-13 server: home check for several vehicles
    home_check named one vehicle. It now takes a list of {imei, latitude,
    longitude, radius_m} entries, one per vehicle; a single mapping still
    works. POST /api/1.0/home checks every entry, or only the one imei=
    names, and answers with a result per device. A vehicle away from home
    and not in garage mode raises one notification naming it.
    A device with no position recorded is reported as such instead of being
    measured from 0,0, and an entry missing its IMEI or a coordinate stops
    the server at startup instead of leaving that vehicle silently unchecked.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
2026-09-13 server: tools/device.py to list, inspect, rename, rekey and remove devices
    adddevice.py enrols a device and nothing looked after it afterwards.
    With more than one vehicle there was no way to see them all or when each
    last reported, nor to rename one, replace a leaked key or retire a unit,
    without SQL.
    device.py list
    device.py show <imei>
    device.py rename <imei> <name> [registration]
    device.py rekey <imei> [--psk <64 hex characters>]
    device.py remove <imei> --yes
    show never prints the key. rekey prints the new one once, and --psk
    sets a key chosen in advance, so a unit in the field can be sent firmware
    carrying it before the server switches over. remove takes the device's
    histor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
    [device.py]
2026-09-13 server: show the missing Maps key note without an inline script
    Without a google_maps_api_key the map page wrote its note with an inline
    <script>, which the Content-Security-Policy in deploy/nginx.conf.example
    does not allow - script-src has no 'unsafe-inline' - so behind that proxy
    the map area was simply blank. The page now marks whether a key is
    configured and track.js writes the note.
    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
2026-09-13 server: document the multi-vehicle server, tls_telemetry and the tools
    README: installing with uv on Python 3.12, running the tools on the
    venv's interpreter, TRACKER_THREADS, how a request names its device and
    what the web UI's pages are, tools/device.py, where the certificates are
    made, and the firmware image exposure on the TLS port.
    config.yaml.example documents tls_telemetry, tls_backlog, api_base, the
    home_check list and an optional default_device, and warns that
    slim_response breaks current firmware; PROTOCOL.md says the same about
    slim_response and TLS telemetry.
    certs/gen_certs.sh wrote the firmware header to ../src/ca_cert.h, which
    does not exist beside the server, so it failed af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
2026-09-13 retry a failed A-GNSS fetch and only use GNSS priority when starved
    A key-on on 2026-09-13 lost two and a half minutes of telemetry: the single
    A-GNSS fetch at the start of the cold search timed out (-116, HTTP 0),
    nothing asked again until the next cold collect, and gnss_collect() held
    GNSS priority mode for the whole search by re-arming it every 30 s, during
    which the modem dropped off the network.
    - Retry the in-search fetch AGNSS_RETRIES (2) more times,
    AGNSS_RETRY_INTERVAL_MS (15 s) apart, from inside the fix wait and only
    while registered, so the receiver keeps searching between attempts.
    - Count consecutive PVT epochs flagged NOT_ENOUGH_WINDOW_TIME in the event
    handler and requ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
    [config.h]
2026-09-13 firmware: commit the Connect Kit's GNSS antenna settings
    The Connect Kit's GNSS LNA is powered from the nRF9151's COEX0 pin, which the
    modem only drives once the modem_antenna library has sent AT%XCOEX0. NCS
    turns that library on only for Nordic's own boards, and the settings lived in
    the gitignored makerdiary.conf, so a fresh clone built Connect Kit firmware
    that could not see a satellite.
    They now live in boards/nrf9151_connectkit_nrf9151_ns.conf, which Zephyr
    applies to every Connect Kit build; makerdiary.conf stays an optional local
    overlay. Also corrects build.sh's comments, which called the DK the default
    profile and credited the antenna setup to the board target.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
2026-09-13 firmware: arm the watchdog for tracker builds only
    Since 0.4.36 a missed watchdog feed really resets the SoC, but the bench
    harnesses - the board test, provisioning mode, K-wire discovery, the CAN and
    K-line tests, the accel, voltage and L-sense streams, the CAN bench agent and
    the LTE power test - wait in loops that never feed it, so each would reset
    about 35-45 s in. main() now arms the watchdog only when none of them is
    built in.
    Compile-tested (tracker and PROV=1 builds); not yet run on a board.
    Claude-Session: https://claude.ai/code/session_018qedd7M9dswRwiNYyPeaoJ
    [main.c]
2026-09-13 firmware: sleep instead of idling awake when there is no position
    A record needs a position, so with no fix since boot collect_data() builds
    nothing, and sleep is only entered from STATE_SEND: a unit that started where
    GNSS could not see the sky - an underground car park after a key-off update,
    say - stayed awake with GNSS searching until a fix turned up.
    With the ignition off it now goes to sleep, and its timed wakes search for a
    first fix on the 1st, 2nd, 4th, 8th and 16th wake and then every 16th. The
    docs now say that nothing is sent before the first fix.
    Compile-tested; not yet run on a board.
    Claude-Session: https:/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
    [main.c]
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2026-09-13 docs, ifmcu: hold DFU/RST while powering up to reach the UF2 bootloader
    Makerdiary's docs and the interface MCU firmware agree that the bootloader is
    entered by holding DFU/RST while the board powers up; pressing the button
    while it runs only resets the nRF9151. The docs, ifmcu/build.sh and
    QUICKSTART.md said to double-press it. On the carrier board the 12V has to
    be off as well, since it powers the Connect Kit through its battery connector.
    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
2026-09-14 docs: drop the accelerometer defect note for v3.0-v3.3 boards
    Nobody is going to build a board before v3.4, and the note linked to a rework
    procedure that was never written.
    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
2026-09-14 firmware: back off after a failed firmware download
    A failed download only bumped the failure counter, so the fota= advert in the
    next reply re-armed the check and the device tried again at the next reply it
    read - within half a minute while driving, stopping GNSS each time. It now
    backs off like every other failed check: 10 minutes, doubling to 80. The
    fota command still overrides it.
    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
2026-09-14 firmware: don't start an update while the engine is running
    STATE_IDLE ran any pending update check on every pass, so a download usually
    began mid-drive: GNSS and telemetry stopped for minutes, then the unit
    rebooted while driving. The main loop now leaves it until the engine stops;
    key-off and timed wakes still check. A manual fota command waits for the
    engine too.
    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
    [main.c]
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2026-09-14 firmware: reset.sh does a pin reset
    reset.sh used a soft (SYSRESETREQ) reset, which leaves the nRF9151 in debug
    interface mode drawing milliamps asleep until a pin reset or power cycle - the
    reason flash.sh already ends with a pin reset. reset.sh now pulses the reset
    line too, so USB re-enumerates and a console has to be reopened, as the docs
    now say. board_test.sh attaches to the console before it resets, so it keeps
    a soft reset of its own.
    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
2026-09-14 firmware: locatenow and tomtomnow take a fresh fix while awake
    STATE_SEND stops GNSS before it runs the commands in a reply, so the record
    locatenow and tomtomnow build waited out the 60 s fix timeout on a stopped
    receiver and reported the last known position. With the ignition on they now
    resume GNSS first.
    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
2026-09-14 firmware: read the IMEI before connecting
    The IMEI was read only inside a successful start-up connect, so a modem that
    registered after the 60 s start-up wait left it unset for the whole boot:
    every send was dropped with 'IMEI not set', and the power-on update check
    asked for imei=unknown. AT+CGSN needs no network, so the IMEI is now read
    straight after the modem library starts, and again after connecting if that
    read failed.
    The board setup pages show imei= in its new place, and their troubleshooting
    entry is now for a modem that has not registered.
    Claude-Session: https://claude.ai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
    [main.c]
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2026-09-14 send a timed report as soon as the modem registers after a failed wake
    A timed wake that misses the 60 s registration timeout leaves the radio
    searching and puts its record in the backlog. When the modem registered a
    minute or two later, the next pass of the sleep loop powered it straight off,
    so the record waited an hour for the next timed wake: on 2026-09-14 the 07:57
    wake gave up, the modem registered at 08:00:31, was powered off at 08:00:57,
    and the record arrived at 08:59 (likewise at 02:49 and 04:51).
    A report that failed for want of registration is now owed. While it is, the
    sleep loop polls every RESEND_POLL_S (30 s), leaves a freshly registered modem
    powered, and reruns the timed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
    [config.h, main.c]
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2026-09-14 report no speed from a stored fix, and none below 2 mph with the ignition off
    Timed check-ins while parked reuse the last stored position, and they also
    repeated that fix's speed for as long as the unit slept: on 2026-09-14 the
    car's hourly records carried 0.68 mph from the fix after its 06:56 reboot, and
    the page showed 1 mph. A fix older than SPEED_FIX_MAX_AGE_MS (10 s) now goes
    out with speed 0, and the IGN_OFF_STOPPED_KMH cut, which only applied to the
    record where the key turned, now applies to every ignition-off record.
    Claude-Session: https://claude.ai/code/session_01PrMNwWmxXpaV3pHK9wGtXQ
    [config.h]
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2026-09-21 adjust battery backup enclosure to address manufacturing issue
    [enclosure.FCStd, enclosure_bottom.step, enclosure_bottom.stl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]
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2026-09-26 swap INA228 for INA238
    [antenna_bias_tee.kicad_sch, battery_voltage_reading.kicad_sch, can_interface.kicad_sch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]
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
